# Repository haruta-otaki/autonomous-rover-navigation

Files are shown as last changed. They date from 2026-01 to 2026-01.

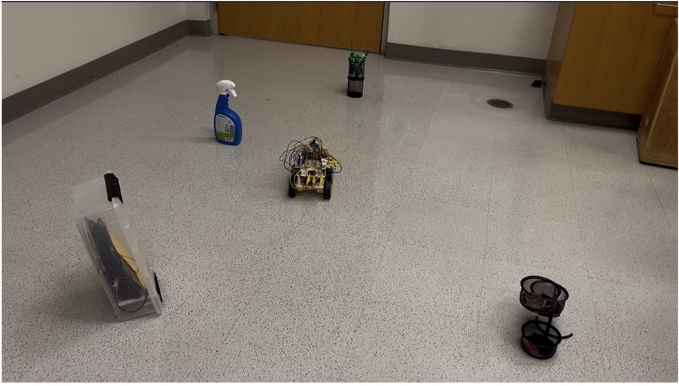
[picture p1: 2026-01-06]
documents/figures/test_environment.jpg

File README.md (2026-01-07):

# Autonomous Rover with Sensor-Based Navigation   

This project explores the design of autonomous, spacecraft-inspired robotic systems through the development of a self-navigating rover. Inspired by planetary exploration rovers (e.g. NASA’s *Perseverance*), the system focuses on autonomous navigation, obstacle detection, and decision-making in uncertain environments. The rover operates by continuously scanning its surroundings using rotating ultrasonic sensors, evaluating alternative paths and selects a direction with minimal perceived interference when an obstacle is detected.

## Overview

This project presents the design and implementation of an autonomous rover capable of sensor-driven navigation and obstacle avoidance. The system integrates ultrasonic distance sensors, micro servo motors, DC drive motors, and motor drivers controlled by an Arduino Mega to perceive its environment, detect obstructions, and dynamically adjust its trajectory toward regions of minimal interference.

Autonomous decision-making is achieved through the application of fundamental principles in motion control, signal timing, and geometric interpretation. In addition to software design, careful consideration was given to power distribution and mechanical constraints, including the use of a 3D-printed chassis and the separation of power domains between logic and actuation components to ensure stable operation.

---

## System Modeling and Software Architecture

The rover interprets physical sensor data using unit conversions, geometric modeling, and trigonometric calculations to estimate its orientation and position. All quantities are computed relative to the rover’s initial position; hence, the initial X and Y coordinates, as well as the heading angle relative to the Y-axis, are initialized to zero.

### Orientation and Position Estimation

The rover estimates its orientation and relative position using wheel kinematics and elapsed time, without relying on external localization systems or sensors. Although servo angles are read directly in degrees, the rover’s global heading cannot be measured directly and is instead inferred from the motion of the wheels during turning maneuvers.

Heading estimation is based on three quantities: the linear velocity of the wheels, the elapsed time spent rotating, and the horizontal separation between the wheels. 

Wheel linear velocity is computed from the wheel diameter (65 mm) and measured motor speed (RPM), yielding:

`v = π · 65 · (RPM / 60)`

The rover’s angular velocity during a turn may then be derived by 
using this linear velocity and the wheel separation (126 mm) of the rover:

`ω = (2 · v / 126) · (180 / π)`

The distance traveled over a control interval Δt is then estimated as:

`d = v · Δt`

The quantities are used to finally update the rover’s kinematic state. The heading angle is updated according to:

`θ(t+1) = θ(t) + ω · Δt`

and the rover’s position in the two-dimensional plane is updated using standard planar motion equations:

`x(t+1) = x(t) + d · cos(θ)`
`y(t+1) = y(t) + d · sin(θ)`

The proposed incremental kinematic update loop enables continuous real-time estimation of the rover’s orientation and relative X–Y position throughout autonomous operation.

---

## Navigation Algorithm

The rover’s autonomous navigation logic is structured around a **two-stage reactive path optimization process** consisting of a *reservation phase* and a *fulfillment phase*.

1. **Reservation Phase**  
   - Front-mounted ultrasonic sensor sweeps 45°–135°
   - Flags when obstacle is detected within 25 cm 
   - Rover brakes and transitions to fulfillment phase

2. **Fulfillment Phase**  
   - Rear-mounted ultrasonic sensors perform a full 360° scan
   - Direction with maximum clearance is returned
   - Rover rotates toward the optimal rotation angle
   - Heading change is estimated via wheel kinematics and elapsed time
   - Flags when rover rotation aligns within ±5° of the optimal heading
   - Rover halts left-turn maneuver andresumes forward motion 

---

## Power Distribution and Hardware Considerations

The rover employs multiple isolated power domains to ensure reliable operation and prevent electrical instability. Four batteries are used to independently supply power to the Arduino, the front and rear L298N motor drivers, and the servo motors.

Each pair of TT DC motors connected to an L298N motor driver requires a continuous 6 V supply. The isolation of the motor power from the Arduino prevents voltage drops and noise. Servo motors present an additional constraint: under load, they draw up to 650 mA, exceeding the Arduino’s maximum current output of approximately 500 mA. Furthermore, servo motors are not designed to accept a 9 V input, as excessive voltage can lead to overheating or permanent damage; hence, an LM7805 voltage regulator is used to step down the 9 V battery input to a stable 5 V supply dedicated to the servo motors.

---

## Repository Structure

```text
autonomous-rover/
├── README.md
│
├── docs/
│   ├── figures/
│      ├── circuit_diagram.png  # circuit diagram of the autonomous rover
│      ├── chassis_layers.png   # configurations of the 3D Print
│      └── test_environment.jpg # testing environment for the rover
│
├── firmware/
│   ├── rover_automation.i/
│   │   ├── rover_automation.i.ino
│
├── hardware/
    ├── Rover_Chassis_Bottom_Layer.stl
    ├── Rover_Chassis_Bottom_Layer.stl
```

## Results

The performance of the autonomous rover was primarily evaluated through video recordings of its operation, as autonomous navigation and real-time path optimization are not easily captured using scalar performance metrics. A full demonstration of the rover’s behavior may be viewed in the accompanying YouTube video:

 [**▶️ Demonstration Video:**](https://youtu.be/_U4xwGOMszU)

Testing was conducted within a confined artificial environment bounded by four walls and populated with randomly placed obstacles. To ensure consistency and fairness during evaluation, only obstacles with uniform dimensions were used. This constraint was necessary because the ultrasonic sensors operate at a fixed height; obstacles with irregular or non-uniform geometries fall outside the design assumptions of the sensing system and could lead to inaccurate or misleading distance measurements.

---

## Discussion

The rover consistently and successfully navigated the test environment across multiple trials. Its behavior closely matched the designed navigation algorithm, repeatedly executing the expected sequence of halting upon obstacle detection, activating the rear-mounted scanning sensors, rotating toward the direction of maximum perceived clearance, and resuming forward motion.

The rover also demonstrated robust performance in challenging scenarios, including navigation near corners and situations involving multiple surrounding obstacles. The consistent success observed across trials also reflects the effectiveness of the rover’s power distribution and mechanical design as no instances of component overheating, electrical malfunction, or structural instability were observed during testing. 

## Future Improvements

The autonomous rover developed in this project does not actively use the computed real-time X and Y position coordinates due to the absence of a wireless transceiver as well as the absense of higher-level behaviors to leverage the positional data. 

### Wireless Communication and Remote Control
A natural next step for this project is the integration of a **LoRa communication module**, a long-range, low-power radio technology designed for transmitting small data packets over extended distances. The enhancement would enable remote telemetry, allowing real-time transmission of position and sensor data without a physical connection. and support a manual control mode, where the rover may be operated through user inputs.

### Improved Motion Accuracy
The accuracy of the rover’s motion and sensor-derived data could be significantly improved through the addition of **wheel encoders**. The current system estimates movement using theoretical wheel RPM values, which may deviate due to surface friction, slippage, and mechanical inefficiencies. Wheel encoders would provide direct feedback on wheel rotation, enabling more precise distance estimation.

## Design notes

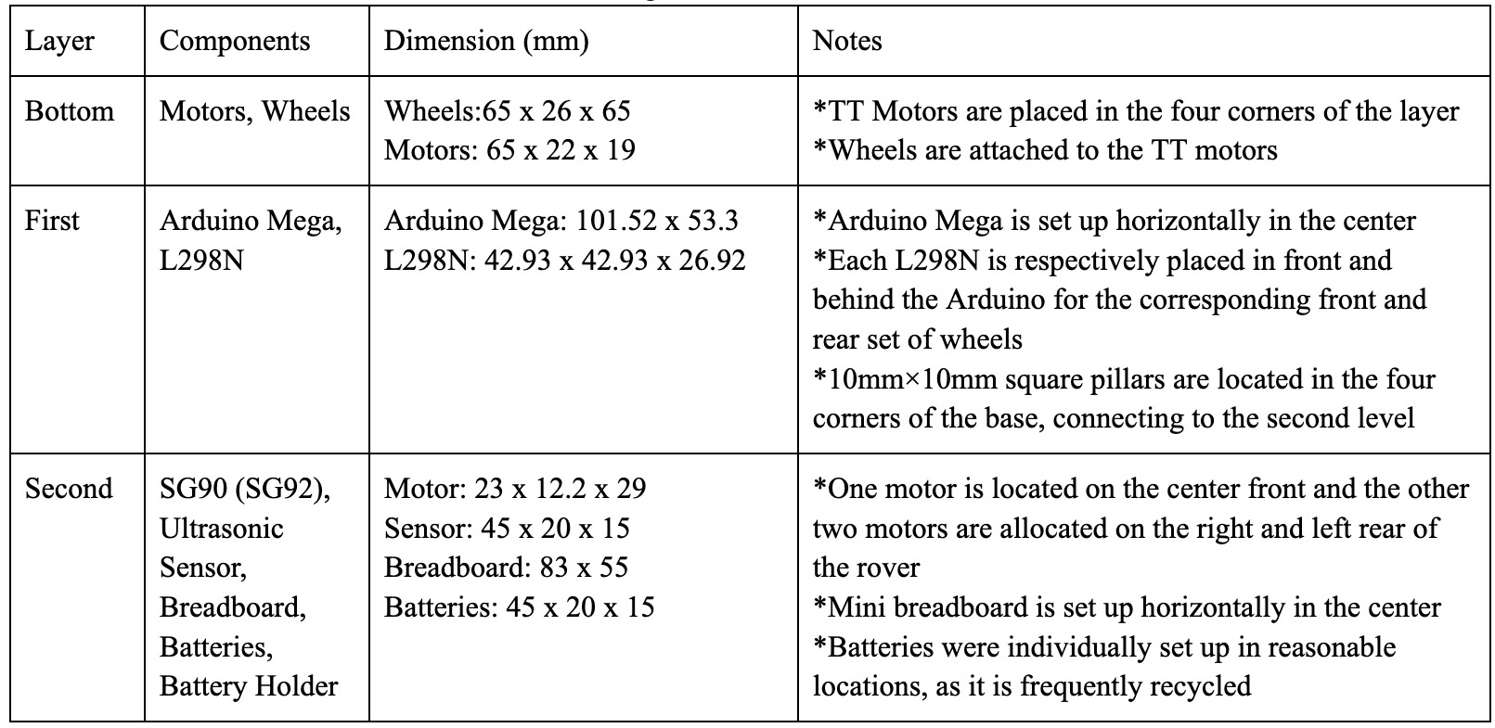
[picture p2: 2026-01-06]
documents/figures/chassis_layers.jpg

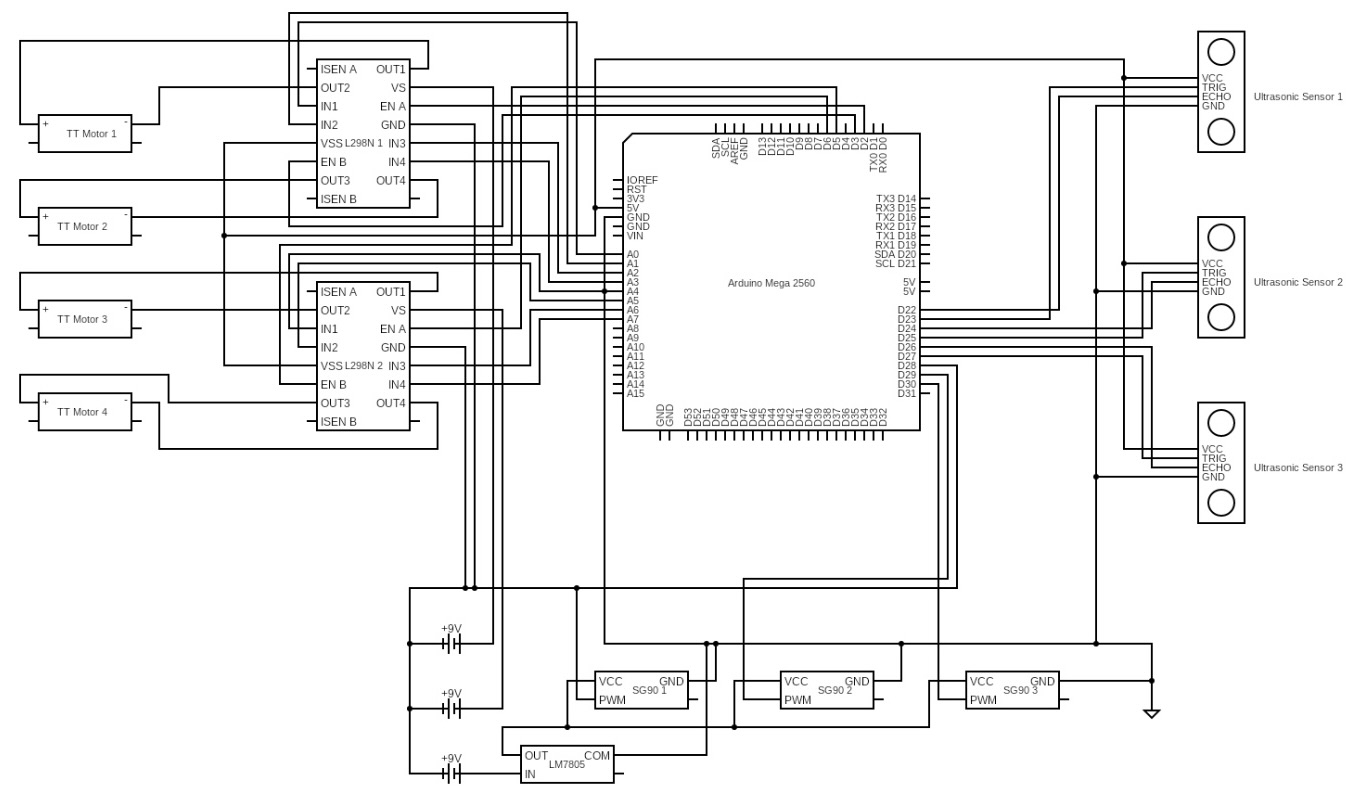
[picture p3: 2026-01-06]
documents/figures/circuit_diagram.jpg

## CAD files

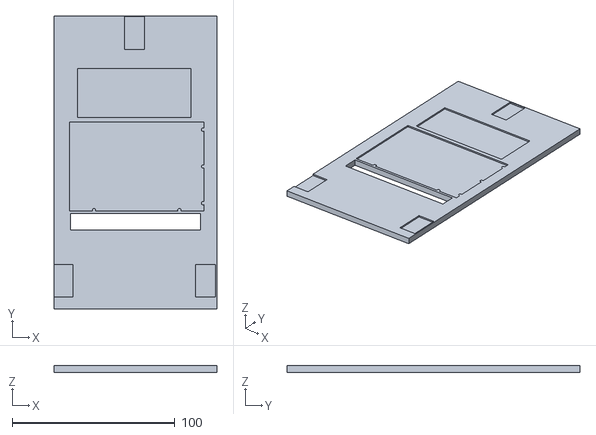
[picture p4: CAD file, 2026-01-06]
hardware/Rover_Chassis_Top_Layer.stl
100.0 x 180.0 x 4.00

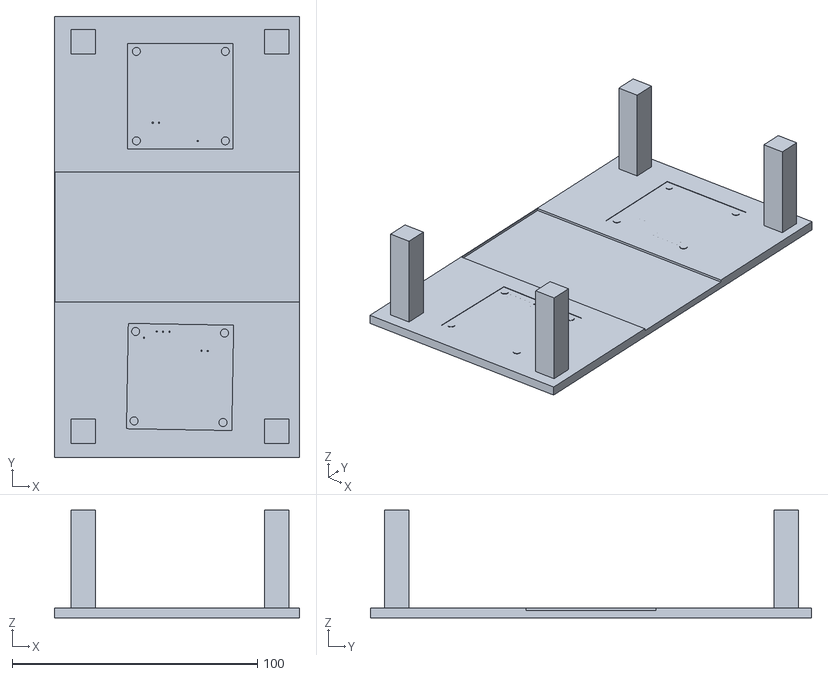
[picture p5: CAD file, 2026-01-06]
hardware/Rover_Chassis_Bottom_Layer.stl
100.0 x 180.0 x 44.0

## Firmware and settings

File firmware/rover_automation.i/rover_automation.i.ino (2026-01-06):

#include <Servo.h>

// =======================================================
// Hardware Configuration
// =======================================================

//pins designated to the front right TT motor 
const int motor_1_pin_1 = A0;
const int motor_1_pin_2 = A1;
const int motor_1_pin_EN = 2;

//pins designated to the front left TT motor 
const int motor_2_pin_1 = A2;
const int motor_2_pin_2 = A3;
const int motor_2_pin_EN = 3;

//pins designated to the back right TT motor 
const int motor_3_pin_1 = A4;
const int motor_3_pin_2 = A5;
const int motor_3_pin_EN = 5;

//pins designated to the back left TT motor 
const int motor_4_pin_1 = A6;
const int motor_4_pin_2 = A7;
const int motor_4_pin_EN = 6;

//pins designated to the front ultrasonic sensor 
const int trig_pin_1 = 23;
const int echo_pin_1 = 22;

//pins designated to the rear left ultrasonic sensor 
const int trig_pin_2 = 25;
const int echo_pin_2 = 24;

//pins designated to the rear right ultrasonic sensor 
const int trig_pin_3 = 27;
const int echo_pin_3 = 26;

// =======================================================
// State and Kinematics
// =======================================================

//monitor state of the rover
enum RoverState {DRIVE, TURN, STOP};
RoverState rover_state = DRIVE;

//constants for deriving the x, y and angular coordinates for the rover
const float Pi = 3.1415926535; 
const float wheel_seperation = 13; 
const float wheel_diameter = 6.5; 
const float turn_circumference = wheel_seperation * Pi;
const float wheel_circumference = wheel_diameter * Pi;
const float rpm = 100; 
const float wheel_velocity = (rpm / 60) * wheel_circumference; 

//time for the servo motor to physically reach the commanded position
const int interval = 50; 

//variables 
float wheel_angular_velocity = 0;
float angle = 0; 
float x = 0; 
float y = 0; 
float r = 0; 

unsigned long time; 
unsigned long turn_time; 

//monitors the previous time the rover was at the particular state
unsigned long travel_timestamp = 0; 
unsigned long turn_timestamp = 0; 
unsigned long regular_timestamp = 0; 

// =======================================================
// Initialization
// =======================================================

//monitors round-trip travel time of the produced sound wave 
long duration = 0; 

//distance detected by each of the ultrasonic sensors 
float distance_1 = 0; 
float distance_2 = 0; 
float distance_3 = 0; 

//the sweep increments for the servo motors
int increment_1 = 10; 
int increment_2 = 10; 

//dictionary to store the surrounding distance data during fulfillment phase
float angle_data[360]; 

//front ultrasonic sensor 
Servo servo1;
//rear left ultrasonic sensor 
Servo servo2;
//rear right ultrasonic sensor 
Servo servo3;

int servo_position_1 = 0; 
int servo_position_2 = 0; 

void setup() {
  // put your setup code here, to run once:
  pinMode(motor_1_pin_1, OUTPUT);
  pinMode(motor_1_pin_2, OUTPUT);

  pinMode(motor_2_pin_1, OUTPUT);
  pinMode(motor_2_pin_2, OUTPUT);

  pinMode(motor_1_pin_EN, OUTPUT);
  pinMode(motor_2_pin_EN, OUTPUT);
    
  pinMode(motor_3_pin_1, OUTPUT);
  pinMode(motor_3_pin_2, OUTPUT);

  pinMode(motor_4_pin_1, OUTPUT);
  pinMode(motor_4_pin_2, OUTPUT);

  pinMode(motor_3_pin_EN, OUTPUT);
  pinMode(motor_4_pin_EN, OUTPUT);


  pinMode(trig_pin_1, OUTPUT);
  pinMode(echo_pin_1, INPUT);

  pinMode(trig_pin_2, OUTPUT);
  pinMode(echo_pin_2, INPUT);

  pinMode(trig_pin_3, OUTPUT);
  pinMode(echo_pin_3, INPUT);

  //assign PWM signal pin of each servo to a digital pin
  servo1.attach(28);
  servo2.attach(29);
  servo3.attach(30);

  //initialize initial position of the servo motor to align with the y-axis 
  servo_position_1 = 90; 
  servo1.write(90);

  Serial.begin(9600);
}

// =======================================================
// Main Control Loop
// =======================================================

void loop() {
  //put your main code here, to run repeatedly:
  time = millis(); 

  //PWM adjusts the speed of the TT motors as a ratio
  //as the PWM ranges from 0 to 255, a half value of 127 allows the RPM of the TT motors to be equal to 100 (200 divided by 2)
  analogWrite(motor_1_pin_EN, 127);
  analogWrite(motor_2_pin_EN, 127);
  analogWrite(motor_3_pin_EN, 127);
  analogWrite(motor_4_pin_EN, 127);

  // reservation condition
  if (distance_1 < 25) {
    //initialize coordinates
    r =((time - travel_timestamp) / 1000)* wheel_velocity; 
    y = r * sin((angle - 90) * (Pi/180));
    x = r * cos((angle - 90) * (Pi/180));

    Serial.print("x: ");
    Serial.println(x);
    Serial.print("y: ");
    Serial.println(y);

    //brake the rover
    rover_state = STOP;
    digitalWrite(motor_1_pin_1, HIGH);
    digitalWrite(motor_1_pin_2, HIGH);

    digitalWrite(motor_2_pin_1, HIGH);
    digitalWrite(motor_2_pin_2, HIGH);

    digitalWrite(motor_3_pin_1, HIGH);
    digitalWrite(motor_3_pin_2, HIGH);

    digitalWrite(motor_4_pin_1, HIGH);
    digitalWrite(motor_4_pin_2, HIGH);

    //fulfillment step
    //rotate the rear servo motors and log the data 
    for(int servo_position_2 = 0; servo_position_2 < 180; servo_position_2+=10){
      servo2.write(servo_position_2);
      servo3.write(179 - servo_position_2);
      distance_2 = getDistance(trig_pin_2, echo_pin_2, duration);
      distance_3 = getDistance(trig_pin_3, echo_pin_3, duration);
      angle_data[servo_position_2] = distance_2;
      angle_data[(servo_position_2 + 180) % 360] = distance_3;
      delay(10);
    }
      
    rover_state = TURN;
    float target_angle = getMaxAngle(angle_data);
    Serial.print("target_angle: ");
    Serial.println(target_angle);
    float current_angle = angle;

    turn_timestamp = millis();
    //rotate the rover until its degree of turn is off by 5 degrees from the target angle 
    while (abs(target_angle - current_angle) > 5.0) {    
      time = millis(); 

      //drive the right-side wheels forward
      //drive the left-side wheels reverse
      digitalWrite(motor_1_pin_1, LOW);
      digitalWrite(motor_1_pin_2, HIGH);

      digitalWrite(motor_2_pin_1, HIGH);
      digitalWrite(motor_2_pin_2, LOW);

      digitalWrite(motor_3_pin_1, LOW);
      digitalWrite(motor_3_pin_2, HIGH);

      digitalWrite(motor_4_pin_1, HIGH);
      digitalWrite(motor_4_pin_2, LOW);
      current_angle = getAngle(time - turn_timestamp);
      if (current_angle < 360) {
        Serial.print("current_angle: ");
        Serial.println(current_angle);
      }
    }

  //update angle and time stamp for the turn event
    angle = current_angle;
    travel_timestamp = time;
  } else {
    //drive all wheels forward
    rover_state = DRIVE;
    digitalWrite(motor_1_pin_1, LOW);
    digitalWrite(motor_1_pin_2, HIGH);

    digitalWrite(motor_2_pin_1, LOW);
    digitalWrite(motor_2_pin_2, HIGH);

    digitalWrite(motor_3_pin_1, LOW);
    digitalWrite(motor_3_pin_2, HIGH);

    digitalWrite(motor_4_pin_1, LOW);
    digitalWrite(motor_4_pin_2, HIGH);
  }

  //rotate the front servo motors to sweep between 45 degrees and 135 degrees 
  for(int servo_position_1 = 45; servo_position_1 < 135; servo_position_1+=10){
    servo1.write(servo_position_1);
    distance_1 = getDistance(trig_pin_1, echo_pin_1, duration);
    delay(10);
  }

  for(int servo_position_1 = 135; servo_position_1 > 45; servo_position_1-=10){
    servo1.write(servo_position_1);
    distance_1 = getDistance(trig_pin_1, echo_pin_1, duration);
    delay(10);
  }
}

// =======================================================
// Sensing Utilities
// =======================================================

//retreive the distance to the nearest foreign object using an ultrasonic sensor
float getDistance(int trig_pin, int echo_pin, long duration) {
  digitalWrite(trig_pin, LOW);
  delayMicroseconds (2);
  // Sets the trig_pin on HIGH state for 10 micro seconds
  digitalWrite(trig_pin, HIGH);
  delayMicroseconds (10);
  digitalWrite(trig_pin, LOW);
  // Reads the echoPin, returns the sound wave travel time in microseconds
  duration = pulseIn(echo_pin, HIGH);
  // Calculating the distance in (cm)
  return duration * 0.034 / 2;
}

// =======================================================
// Motion and Geometry Utilities
// =======================================================

float getAngle(float time) {
  return ((2 * wheel_velocity) / wheel_seperation) * (time / 1000) * (180/Pi); 
}

//retreive the angle thatrecorded the maximum distance to the nearest foreign object 
float getMaxAngle(float angle_data[]) {
  float angle = 0; 
  float maximum_distance = 0; 
  for (int i = 0; i < 360; i++) {
    if (maximum_distance < angle_data[i]) {
      maximum_distance = angle_data[i];
      angle = i; 
    }
  }
  return angle; 
}
